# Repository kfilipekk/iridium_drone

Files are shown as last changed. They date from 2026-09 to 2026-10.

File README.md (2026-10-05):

# NAVCORE-SoOP



A 46.5 × 47.2 mm, 6-layer STM32H743 flight controller that navigates without GPS using the Doppler shift of Iridium satellites. It runs ArduPilot with a MatekH743-compatible pinout and also carries the avionics for a TVC rocket lander. Made by Krystian Filipek for my GNSS-denied drone and the Cambridge University Spaceflight Lander Challenge.

<div align="center">

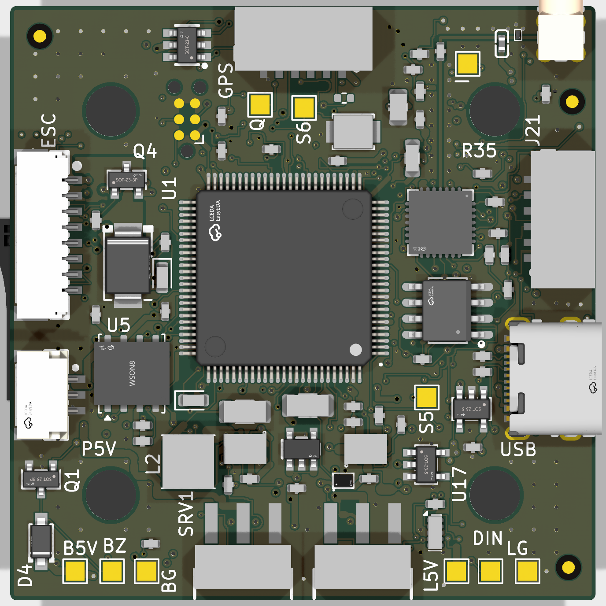
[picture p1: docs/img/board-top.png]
Board Top

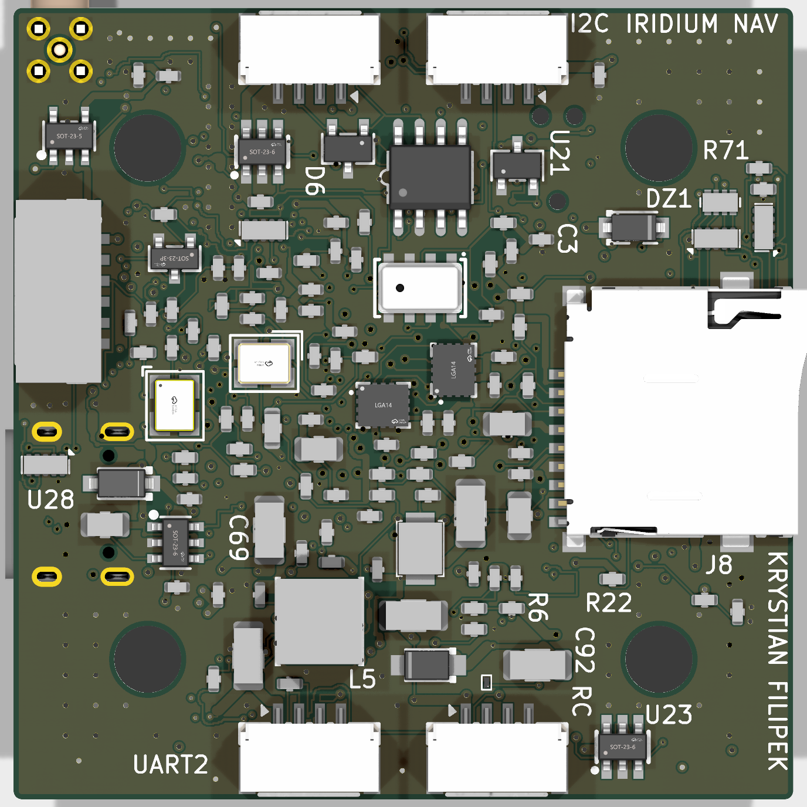
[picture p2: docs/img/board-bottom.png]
Board Bottom


</div>

## Features

### Iridium Navigation
Optical flow and visual-inertial odometry drift without bound over long flights. Iridium NEXT satellites orbit at ~780 km and ~7.5 km/s and transmit continuously at 1616-1626.5 MHz, so the Doppler shift of their bursts gives an absolute position with bounded error (typically 100-200 m) that complements the faster inertial sensors.

- **L-band Receiver** - MAX2112 direct-conversion tuner and OPA2374 baseband filter into the ADCs
- **Antenna Feed** - MMCX port with a current-limited 5 V feed for the active antenna, reported as open, ok or short
- **On-board Navigation** - burst detection, SGP4 orbits and the position solve run on the H743 and feed ArduPilot's EKF as a GPS
- **Spoofing Check** - the real GPS is checked against the Iridium-only fix before it is trusted

### Hardware
| Subsystem | Components |
|---|---|
| MCU | STM32H743VIT6, Cortex-M7 @ 480 MHz, 2 MB flash, 1 MB RAM |
| IMUs | ICM-42688-P (SPI1) and ICM-42605 (SPI4) on a separate low-noise 3.3 V rail |
| Barometer | MS5611 on I2C2 |
| Storage | W25Q128 flash for the orbit catalogue, microSD over SDIO |
| Power | 3S-5S input, TVS and reverse-polarity protection, two LMR33630 bucks (5 V 1.6 A system, 5 V 2.1 A payload) and three 3.3 V LDOs |
| Connectors | Latching JST-GH on every cable port, two servo headers, MMCX, USB-C, TC2030 SWD pads |
| Protection | ESD clamp on every cable-facing signal, series resistors on the motor, telemetry, current, lidar and servo lines |

### Layer Stackup
```
F.Cu:   RF, crystals, MCU fanout
In1.Cu: Continuous ground plane
In2.Cu: SPI, SDIO and I2C
In3.Cu: UARTs, PWM and slow I/O
In4.Cu: Power planes (+5V, +5V_PAYLOAD, +3V3, VBAT)
B.Cu:   Sensors, RF receiver, DroneCAN, bucks
```

### Supported Platforms
- **GNSS-denied Quadcopter** - 30.5 mm stack mount, DShot ESC on `J2`, optical flow on `J14`, lidar on `J11`, companion computer on `J21`, DroneCAN on `J6`
- **TVC Rocket Lander** - two servo outputs (`J17`, `J23`) on the payload rail and 6-DoF logging to microSD

### How It Compares
| | NAVCORE-SoOP | SpeedyBee F405 V4 | Matek H743-SLIM V3 | Pixhawk 6C |
|---|---|---|---|---|
| MCU | STM32H743 | STM32F405 | STM32H743 | STM32H743 + F103 |
| IMUs | ICM-42688-P + ICM-42605 | ICM-42688-P | ICM-42688-P + ICM-42605 | ICM-42688-P + BMI088 |
| Input | 3-5S | 3-6S | 2-8S | power module |
| Port ESD | every cable signal | none stated | none stated | none stated |
| Position without GNSS | Iridium Doppler, 100-200 m | none | none | none |

It has no OSD and no 9-12 V video rail, and it takes 5S at most.

## Getting Started

### Prerequisites
- **KiCad 9** with the `pcbnew` Python module
- **Python 3** with `pip install -r requirements.txt`
- **ArduPilot toolchain** for the firmware (`tools/build_firmware.sh` pins Copter-4.7.0)

### Checking the Board
1. Clone the repository:
   ```bash
   git clone https://github.com/kfilipekk/iridium_drone.git
   cd iridium_drone
   ```

2. Run KiCad's own checks:
   ```bash
   kicad-cli pcb drc --severity-error NAVCORE-SoOP.kicad_pcb
   kicad-cli sch erc NAVCORE-SoOP.kicad_sch
   ```

3. Run the board checks:
   ```bash
   python3 tools/check_design.py
   python3 tools/check_connectors.py
   python3 tools/check_power_cut.py
   python3 tools/check_ratings.py
   ```

4. Build the firmware:
   ```bash
   bash tools/build_firmware.sh
   ```

### Ordering
The JLCPCB files are in `fab/`: the Gerber and drill bundle, BOM, pick-and-place and schematic PDF. Order 6 layers, 1 oz outer copper, no impedance control, epoxy-filled and capped vias, ENIG, and top and bottom assembly.

## Repository Structure

```
├── NAVCORE-SoOP.kicad_pcb   # PCB
├── NAVCORE-SoOP.kicad_sch   # Schematic, generated from tools/design.py
├── fab/                     # JLCPCB order files
├── firmware/                # ArduPilot hwdef, the SoOP backend and the on-board navigation
├── tools/                   # Design model, generators and checks
├── cad/                     # OpenSCAD airframe and clearance models
├── sim/                     # SPICE decks for the analogue blocks
├── sitl/                    # ArduPilot SITL scenarios
└── libraries/               # Footprint and symbol libraries
```

## Applications

I made this project to explore:
- Navigation from signals of opportunity instead of GPS
- Six-layer mixed-signal PCB design with an RF front end
- ArduPilot drivers and EKF integration
- Automated checks for a hardware design

## Future Plans

- Bench-test the Iridium receive chain with the HC610 antenna
- Rev E: a third IMU, 6S input and a 9-12 V video rail

<div align="center">

Developed by [kfilipekk](https://github.com/kfilipekk)

</div>

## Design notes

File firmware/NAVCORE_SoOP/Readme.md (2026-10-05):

# NAVCORE_SoOP

ArduPilot hardware definition for the NAVCORE-SoOP flight controller.

## Introduction

NAVCORE-SoOP is a 46.5 x 47.2 mm, 6-layer STM32H743 flight controller built to test
navigation without GPS. It works out position from the Doppler shift of Iridium satellite
signals, which is a rough but *absolute* fix, so the error stays bounded instead of growing
with time the way a camera or flow-based estimate does.

The pinout follows the MatekH743 wherever the layout allowed, so stock ArduPilot MatekH743
binaries boot on it for bring-up, on one IMU (see IMU Orientation). This hwdef gives the
board its own ID, reaches both IMUs with the right rotations, and describes only the hardware
that is actually populated.

Project repository: <https://github.com/kfilipekk/iridium_drone>

## Features and Specifications

* Processor: STM32H743VIT6, 480 MHz, LQFP-100
* Flash for logging: microSD (SDMMC1, 4-bit) and a W25Q128 16 MB SPI flash used for the
  Iridium TLE catalogue
* IMUs: ICM-42688-P (SPI1) and ICM-42605 (SPI4), both on their own 3.3 V analogue rail
* Barometer: MS5611 (I2C, address 0x77)
* Compass: none on board, external I2C compass on the GPS connector
* SoOP receiver: MAX2112 L-band tuner (I2C2) and OPA2374 baseband amplifiers into ADC1/ADC2,
  with a current-limited, monitored 5 V feed to the active antenna on the MMCX port
* Power: 3S to 5S input, reverse-polarity protected; a 5 V buck for the board, a second
  switchable 5 V buck for payloads, and 3.3 V regulators
* Protection: every cable-facing signal is clamped at its connector
* Physical: 46.5 x 47.2 mm, 30.5 mm stack pattern, 1.6 mm, 6 layers

There is no on-board compass and no analogue OSD chip by design.

## Where to Buy

Not commercially available. NAVCORE-SoOP is an open-source hardware project; the design
files are in the repository linked above and there is no vendor.

## Pinout

### Connectors

Every cable port is a latching JST-GH 1.25 mm connector.

| Reference | Type | Function |
| --- | --- | --- |
| J1 | USB-C | USB, ESD protected |
| J2 | JST-GH 8P | 4-in-1 ESC: power, motors, current, telemetry |
| J3 | JST-GH 6P | GPS and external compass: 5 V, TX, RX, SCL, SDA, GND |
| J5 | JST-GH 4P | RC receiver: 5 V, TX, RX, GND |
| J6 | JST-GH 4P | CAN1: 5 V payload, CANH, CANL, GND |
| J8 | microSD | Logging |
| J9 | JST-GH 4P | I2C1: 5 V, SCL, SDA, GND |
| J11 | JST-GH 4P | SERIAL2: 5 V payload, TX, RX, GND |
| J12 | MMCX | SoOP antenna, with 5 V for its LNA |
| J14 | JST-GH 6P | SPI3 optical flow: 3.3 V, SCK, MISO, MOSI, CS, GND |
| J17 | 1x3 2.54 mm header | Servo 1: PWM7, 5 V payload, GND |
| J19 | Tag-Connect TC2030 | SWD: 3.3 V, SWDIO, NRST, SWCLK, GND |
| J21 | JST-GH 6P | SERIAL1 (UART7), Pixhawk TELEM order: 5 V, TX, RX, CTS, RTS, GND |
| J22 | JST-GH 3P | Payload 5 V for a camera or VTX |
| J23 | 1x3 2.54 mm header | Servo 2: PWM8, 5 V payload, GND |

The LED strip and the buzzer are on solder pads (5 V, data or drain, GND).

### J2, the ESC connector

| Pin | Signal |
| --- | --- |
| 1 | GND |
| 2 | VBAT |
| 3 | Motor 1 |
| 4 | Motor 2 |
| 5 | Motor 3 |
| 6 | Motor 4 |
| 7 | Current sense |
| 8 | ESC telemetry (RX only) |

This matches the Betaflight pin order for the SpeedyBee F405 V4.

## UART Mapping

| Serial | Protocol | Port | Notes |
| --- | --- | --- | --- |
| SERIAL0 | OTG1 | USB | |
| SERIAL1 | Telem1 | UART7 | J21, with CTS/RTS |
| SERIAL2 | Spare | USART1 | J11 |
| SERIAL3 | GPS1 | USART2 | Default GPS, on J3 |
| SERIAL4 | Spare | USART3 | Not brought out on this board |
| SERIAL5 | ESC telemetry | UART8 | RX only, pin 8 of J2 |
| SERIAL6 | | EMPTY | Unassigned: UART4's pins carry PWM5 and PWM7 |
| SERIAL7 | RCin | USART6 | CRSF/ELRS, on J5 |
| SERIAL8 | OTG2 | Not connected | |

## PWM Outputs

Four motor outputs on J2, DShot capable. `MOT_PWM_TYPE` defaults to 6 (DShot600) and the
frame is `FRAME_CLASS 1`, `FRAME_TYPE 1`. Motors 1-2 are on TIM3 and 3-4 on TIM5, each
timer with DMA of its own, so bidirectional DShot works on all four: flash Bluejay to the
ESC, then set `SERVO_BLH_BDMASK` to 15.

PWM 5 and 6 are on test pads TP3 and TP4. PWM 7 and 8 (TIM4) are on the servo headers J17
and J23. PWM 11 and 12 are not brought out.

PWM(13) on PA8 drives an addressable LED strip through a buffer, and `SERVO13_FUNCTION`
defaults to 120 for that purpose.

## RC Input

Connect the RC receiver to J5, which is a JST-GH 1.25 mm 4-pin connector carrying 5 V,
TX, RCin and GND. `SERIAL7_PROTOCOL` defaults to 23, which is CRSF, so CRSF and ELRS
receivers work with no parameter change.

For uni-directional protocols such as SBUS and FPort, set `RC_PROTOCOLS` to 1 to return to
auto-detection. This board provides no dedicated SBUS inverter or RCin pad; all RC input
arrives on the J5 UART.

## Payload Power

A second 5 V buck feeds the payload connectors (J6, J11, J17, J22, J23) and the LED strip
pad. GPIO 83 switches it and is `RELAY1_PIN` with `RELAY1_DEFAULT 0`. The switch is inverted: pin low
leaves the rail on, so the payload is powered from boot. Setting the relay turns it off.

## GPIOs

| GPIO | Pin | Function |
| --- | --- | --- |
| 83 | PA7 | Payload 5 V rail, low = on, `RELAY1_PIN` |
| 84 | PC5 | Antenna 5 V feed enable, high = on from boot |
| 85 | PD10 | Antenna feed fault, from the load switch |
| 86 | PD11 | Not wired, pulled down (reserved for a flow sensor's motion line) |

## CAN

CAN1 is on J6 through an SN65HVD230 transceiver, with `GPIO_CAN1_SILENT` on PD3. The bus
is not terminated on the board. Fit R15 (120 ohm) if the board is at one end of the bus.

## IMU Orientation

Both IMUs are on the bottom of the board. The hwdef declares `ROTATION_YAW_180` for the
ICM-42688-P and `ROTATION_YAW_90` for the ICM-42605, worked out from the footprint pads,
with forward as marked by the silkscreen arrow.

The ICM-42605's chip select is PE11, the pin MatekH743 gives its ICM-20602, so stock
MatekH743 firmware finds only the ICM-42688-P. Check the attitude on the bench before
flying stock firmware, and set `AHRS_ORIENTATION` if it is off.

## RSSI, Airspeed and Analog Pins

There are no user analog inputs and no airspeed pin on this board. RSSI arrives over CRSF
and requires no analog pin. ADC1/ADC2 sample the SoOP receiver's I and Q, and ADC3 the
battery and the antenna feed current.

## Battery Monitoring

The board has an internal voltage sensor and takes current from the ESC's shunt on J2,
pin 7. It is rated for 3S to 5S packs.

The default battery parameters are:

* `BATT_MONITOR` = 4
* `BATT_VOLT_PIN` = 10
* `BATT_CURR_PIN` = 11
* `BATT_VOLT_MULT` = 11.0
* `BATT_AMP_PERVLT` = 25.0

`BATT_AMP_PERVLT` is derived from the ESC's published 40 mV/A scale, with no divider on
this board. It is a property of the current sensor in the ESC and will need to be adjusted
for whichever ESC is attached, or calibrated against a known load.

## Compass

NAVCORE-SoOP does not have a built-in compass, but you can attach an external compass using
I2C on the SDA and SCL pins of the J3 connector, which is the same connector as the GPS.
An external compass is the intended configuration, because a magnetometer placed on this
board would sit within a few millimetres of a 60 A ESC.

## Firmware

Firmware for this board can be found at <https://firmware.ardupilot.org> in the
sub-folder labelled `NAVCORE_SoOP`.

## Loading Firmware

This board does not ship with firmware. Hold BOOT while pressing RESET to start the
STM32's built-in DFU loader (USB ID 0483:df11), then flash the `_with_bl.hex` build following
<https://ardupilot.org/copter/docs/common-loading-firmware-onto-chibios-only-boards.html>.
J19 (SWD) is the fallback if DFU never appears.

## Other Links

* Project repository: <https://github.com/kfilipekk/iridium_drone>
* Board pin map and assembly notes: in the repository under `docs/`

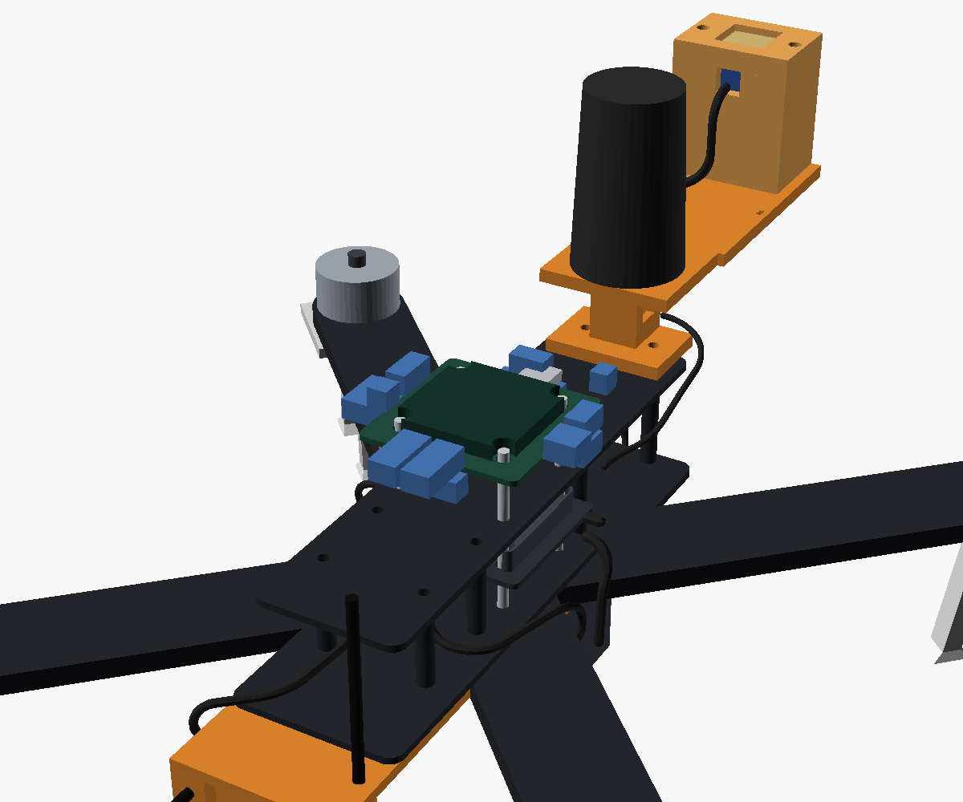
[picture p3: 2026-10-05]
cad/renders/exploded.png

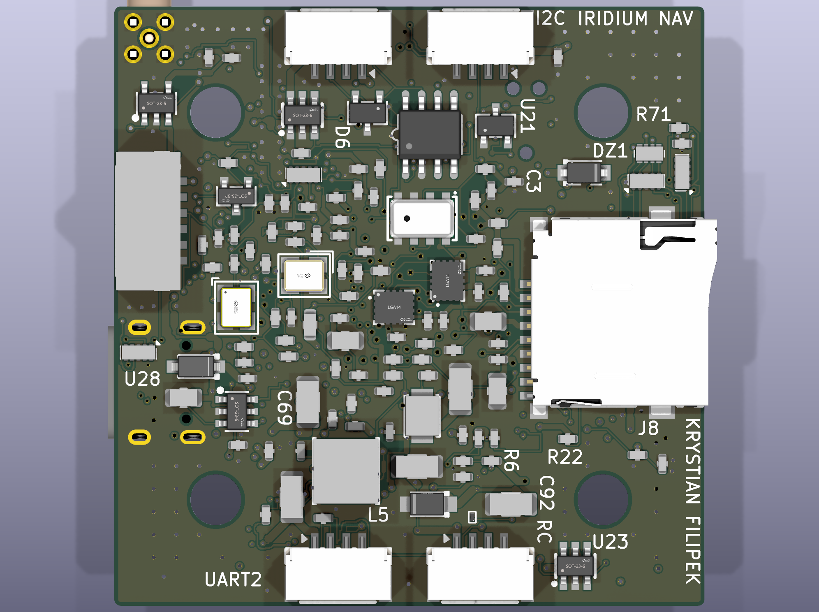
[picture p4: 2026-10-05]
docs/img/render-bottom-flat.png

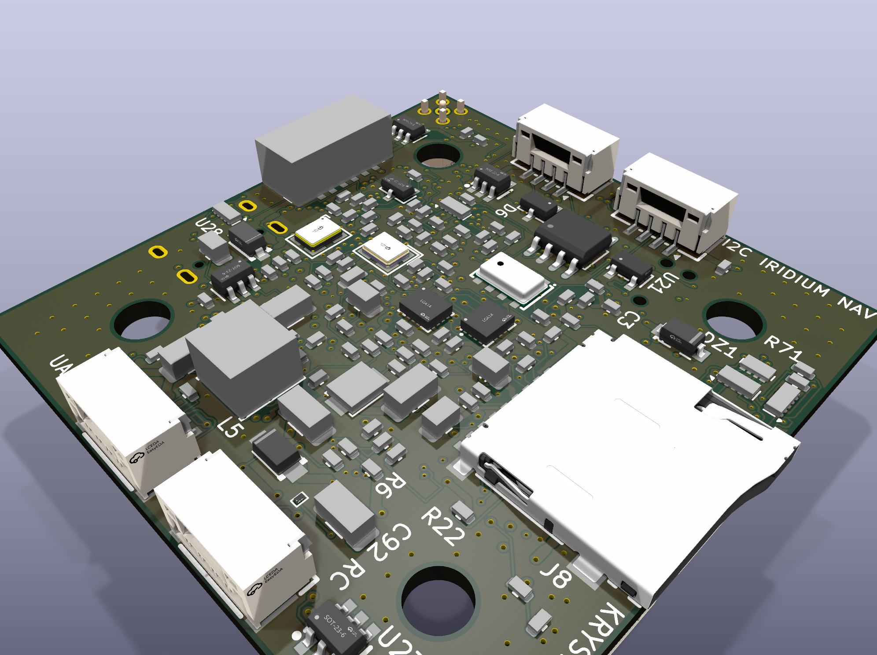
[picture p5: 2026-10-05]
docs/img/render-iso-bottom.png

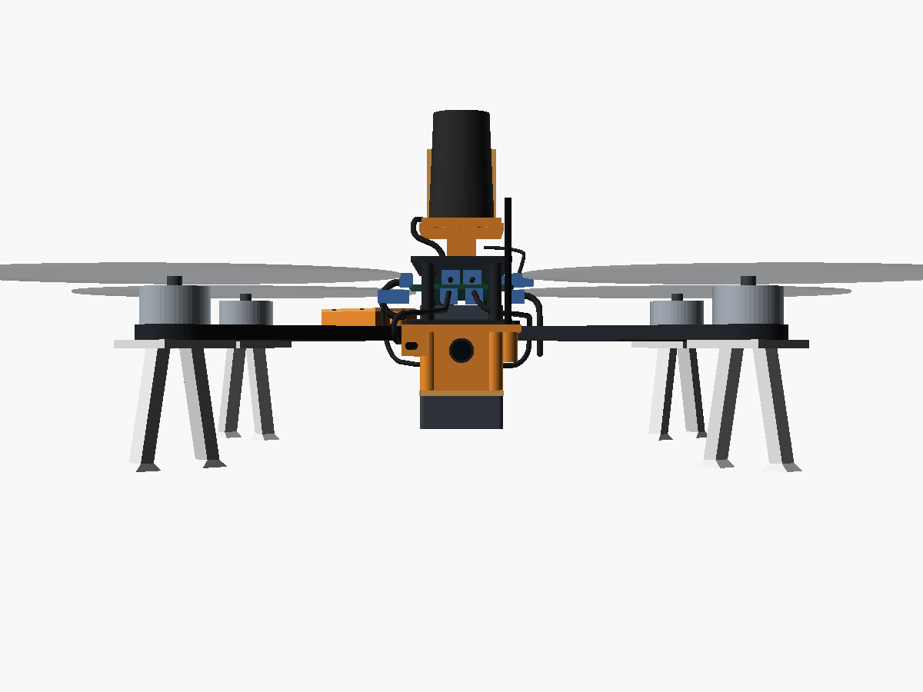
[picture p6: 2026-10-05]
cad/renders/front.png

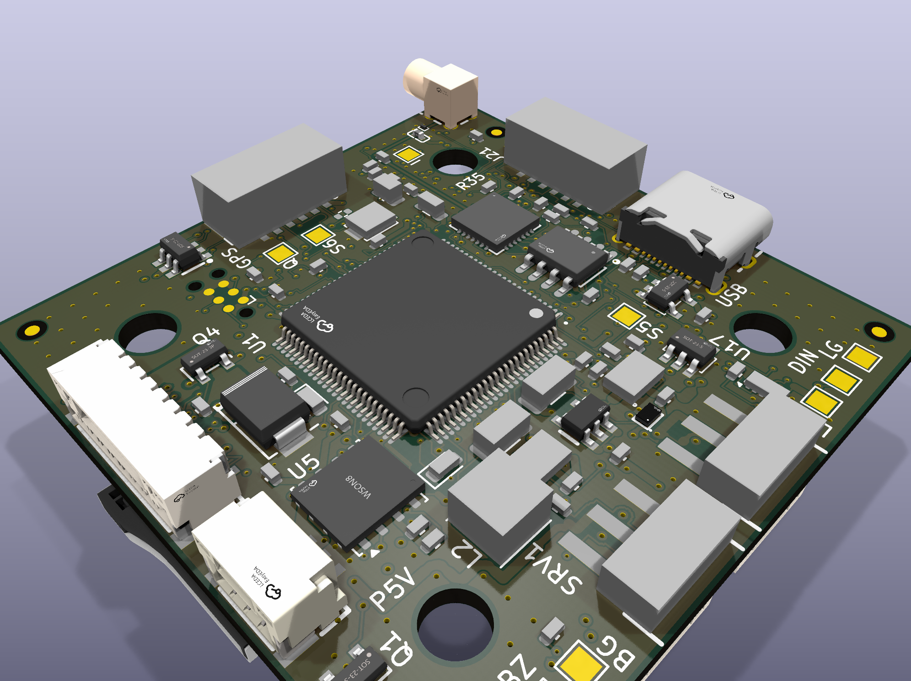
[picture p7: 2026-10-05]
docs/img/render-iso.png

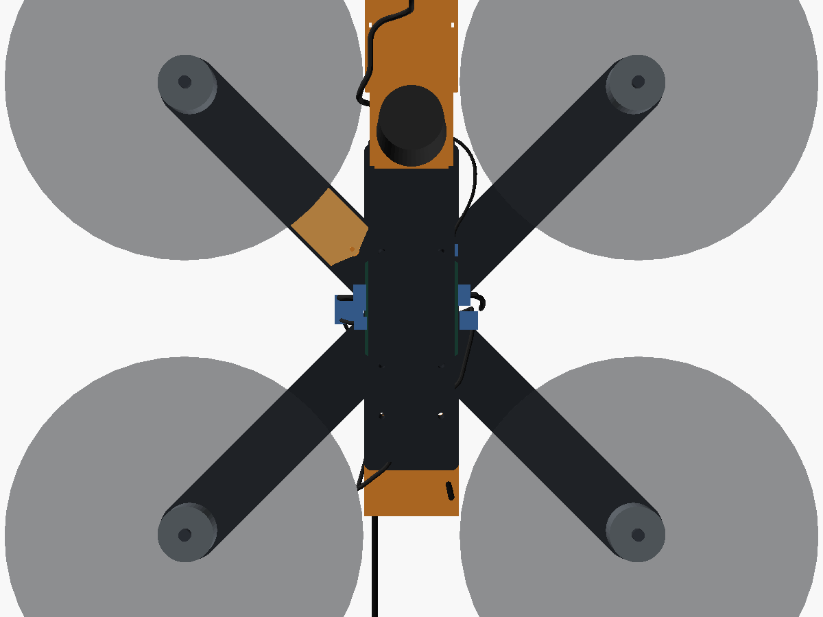
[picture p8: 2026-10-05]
cad/renders/top.png

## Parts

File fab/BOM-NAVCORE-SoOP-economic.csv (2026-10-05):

Comment | Designator | Footprint | LCSC | Qty | DNP
100n | C1,C10,C12,C14,C2,C21,C3,C30,C31,C32,C33,C34,C35,C36,C4,C41,C43,C44,C46,C49,C5,C50,C57,C59,C60,C65,C68,C74,C88,C89,C90,C94,C95,C96 | C_0402_1005Metric | C1525 | 34
10k | R1,R14,R39,R45,R48,R49,R50,R51,R52,R53,R59,R60 | R_0402_1005Metric | C25744 | 12
1u | C11,C13,C26,C27,C28,C51,C67,C75,C78,C79,C80 | C_0402_1005Metric | C52923 | 11
4k7 | R10,R11,R12,R31,R36,R37,R47,R58,R9 | R_0402_1005Metric | C25900 | 9
47k | R22,R23,R24,R25,R26,R27 | R_0402_1005Metric | C25792 | 6
100R | R38,R70,R72,R73,R74,R75 | R_0402_1005Metric | C25076 | 6
100k | R4,R40,R42,R46,R6 | R_0402_1005Metric | C25741 | 5
22u | C22,C23,C69,C70,C92 | C_1206_3216Metric | C5177178 | 5
TPD4E05U06 | U26,U27,U28,U29,U30 | USON-10_2.5x1.0mm_P0.5mm | C138714 | 5
1k | R19,R20,R21,R35 | R_0402_1005Metric | C11702 | 4
100p | C52,C56,C76,C77 | C_0402_1005Metric | C1546 | 4
2u2 | C29,C8,C9 | C_0402_1005Metric | C12530 | 3
1n | C81,C84,C86 | C_0402_1005Metric | C1523 | 3
LMR33630A | U20,U8 | VQFN-12_L3.0-W2.0-P0.65-BL_TI_RNX | C2861505 | 2
4u7 | C6,C7 | C_0805_2012Metric | C354262 | 2
30p | C15,C16 | C_0402_1005Metric | C107004 | 2
10u | C17,C18 | C_1206_3216Metric | C13585 | 2
100n | C19,C66 | C_0402_1005Metric | C131394 | 2
22k | R41,R5 | R_0402_1005Metric | C25767 | 2
24k9 | R43,R7 | R_0402_1005Metric | C25874 | 2
5k1 | R16,R17 | R_0402_1005Metric | C25905 | 2
10u | C45,C93 | C_0805_2012Metric | C1713 | 2
0R | R28,R29 | R_0402_1005Metric | C17168 | 2
10n | C58,C73 | C_0402_1005Metric | C15195 | 2
47n | C61,C63 | C_0402_1005Metric | C82219 | 2
AO3400A | Q1,Q3 | SOT-23-3_L2.9-W1.3-P1.90-LS2.4-BR | C20917 | 2
SRV05-4 | U22,U23 | SOT-23-6_L2.9-W1.6-P0.95-LS2.8-BR | C6454456 | 2
PESD5V0C1BSF | D7,D9 | DSN0603-2_L0.6-W0.3-P0.40-BI | C477955 | 2
STM32H743VIT6 | U1 | LQFP-100_L14.0-W14.0-P0.50-LS16.0-BL | C5271084 | 1
ICM-42688-P | U2 | LGA-14_L3.0-W2.5-P0.50-TL | C1850418 | 1
ICM-42605 | U3 | LGA-14_L3.0-W2.5-P0.50-TL | C2655099 | 1 | DNP
MS5611 | U4 | SENSORS-SMD_MS5611-01BA03 | C15639 | 1
W25Q128JVPIQ | U5 | WSON-8-1EP_6x5mm_P1.27mm_EP3.4x4.3mm | C190862 | 1
TLV75733P | U9 | SOT-23-5_L2.9-W1.6-P0.95-LS2.8-BL-EP | C22399950 | 1
TLV75533 | U10 | SOT-23-5_L3.0-W1.7-P0.95-LS2.8-BR | C404027 | 1
SN65HVD230 | U11 | SOIC-8_L4.9-W3.9-P1.27-LS6.0-BL | C12084 | 1
USBLC6-2SC6 | U12 | SOT-23-6_L2.9-W1.6-P0.95-LS2.8-BL | C2687116 | 1
USB-C | J1 | USB-C-SMD_TYPE-C-16PIN-2MD-073 | C2765186 | 1
ESC 8P | J2 | CONN-SMD_SM08B-GHS-TB-LF-SN | C42376901 | 1
GPS+I2C | J3 | CONN-SMD_XY-SM06B-GHS-TB | C51940119 | 1
RC IN | J5 | CONN-SMD_4P-P1.25_BX-GH1.25-4PWT | C18077720 | 1
CAN 4P | J6 | CONN-SMD_4P-P1.25_BX-GH1.25-4PWT | C18077720 | 1
microSD | J8 | TF-SMD_TF-01A | C91145 | 1
8MHz | Y1 | CRYSTAL-SMD_4P-L3.2-W2.5-BL | C2682774 | 1
SMBJ22A | D1 | SMB_L4.6-W3.6-LS5.3-RD | C113993 | 1
MAX2112 | U13 | TQFN-28_L5.0-W5.0-P0.50-BL-EP3.3 | C596391 | 1
OPA2374 | U14 | SOP-8_L4.9-W3.9-P1.27-LS6.0-BL | C444392 | 1
25MHz TCXO | Y2 | OSC-SMD_4P-L3.2-W2.5-BL | C5563878 | 1
600R@100MHz | L1 | L_0805_2012Metric | C18305 | 1
10uH | L2 | L_APV_ANR4030 | C167879 | 1
120R | R15 | R_0402_1005Metric | C25862 | 1 | DNP
1u | C42 | C_0805_2012Metric | C91185 | 1
10k | R18 | R_0603_1608Metric | C25804 | 1
BLUE | D2 | LED_0603_1608Metric | C965807 | 1
GREEN | D3 | LED_0603_1608Metric | C965804 | 1
BOOT | SW1 | SW_SPST_B3U-1000P | C231329 | 1
RESET | SW2 | SW_SPST_B3U-1000P | C231329 | 1
330R | R34 | R_0402_1005Metric | C25104 | 1
470R | R57 | R_0402_1005Metric | C25117 | 1
COMPANION | J21 | CONN-SMD_XY-SM06B-GHS-TB | C51940119 | 1
1N4148W | D4 | SOD-123F_L2.7-W1.6-LS3.8-RD | C81598 | 1
10uH | L5 | L_APV_ANR5040 | C354610 | 1
PAYLOAD 5V | J22 | CONN-TH_SM03B-GHS-TB-LF-SN | C514175 | 1
74LVC1G17 | U17 | SOT-23-5_L3.0-W1.7-P0.95-LS2.8-BR | C7836 | 1
XC6206P332MR | U21 | SOT-23-3_L2.9-W1.6-P1.90-LS2.8-BR | C5446 | 1
PESD2CANFD24LT | D6 | SOT-23-3_L2.9-W1.6-P1.90-LS2.8-BR | C6952426 | 1
FLOW 6P | J14 | CONN-SMD_XY-SM06B-GHS-TB | C51940119 | 1
SERVO1 | J17 | HDR-SMD_3P-P2.54-H-M_KH-2.54PH-1X3P-L13.5-WT | C20610212 | 1
SERVO2 | J23 | HDR-SMD_3P-P2.54-H-M_KH-2.54PH-1X3P-L13.5-WT | C20610212 | 1
PTVS5V0S1UR | D8 | SOD-123FL_L2.7-W1.8-LS3.8-RD | C5380694 | 1
AP22653 | U24 | SOT-23-6_L2.9-W1.6-P0.95-LS2.8-BR | C2158037 | 1
210k | R61 | R_0402_1005Metric | C58827 | 1
2R2 | R62 | R_0402_1005Metric | C25101 | 1
INA180A2 | U25 | SOT-23-5_L3.0-W1.7-P0.95-LS2.8-BL | C192764 | 1
10p | C91 | C_0402_1005Metric | C32949 | 1
27nH | L6 | L0402 | C113111 | 1
B5819W | D_USB | SOD-123_L2.7-W1.6-LS3.7-RD-1 | C8598 | 1
MMCX-KWE-90 | J12 | MMCX-TH_DL-MMCX-KWE-90 | C2894793 | 1
TMP119 | U19 | DSBGA-6_L1.5-W1.0-R2-C3-P0.40-BL | C22428347 | 1
WST4041 | Q4 | SOT-23-3_L2.9-W1.3-P1.90-LS2.4-BR | C148357 | 1
BZT52C15 | DZ1 | SOD-123_L2.7-W1.6-LS3.7-RD | C173427 | 1
I2C 4P | J9 | CONN-SMD_4P-P1.25_BX-GH1.25-4PWT | C18077720 | 1
SERIAL2 4P | J11 | CONN-SMD_4P-P1.25_BX-GH1.25-4PWT | C18077720 | 1
33R x4 | RN1 | R_Array_Convex_4x0402 | C25501 | 1
2k2 | R71 | R_0402_1005Metric | C25879 | 1

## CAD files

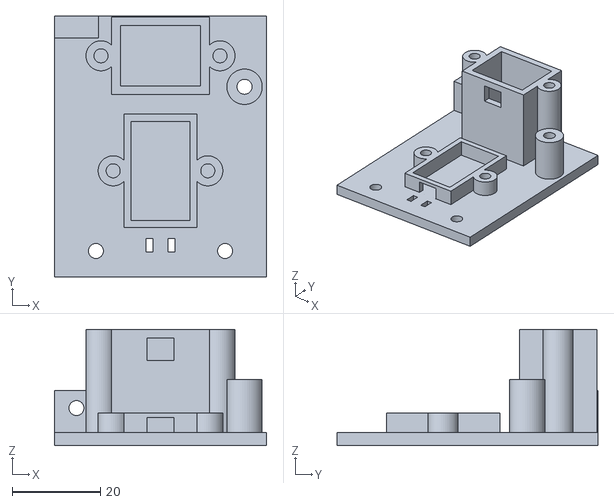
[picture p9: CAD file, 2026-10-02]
cad/print/nose_mount.stl
48.0 x 59.0 x 26.3

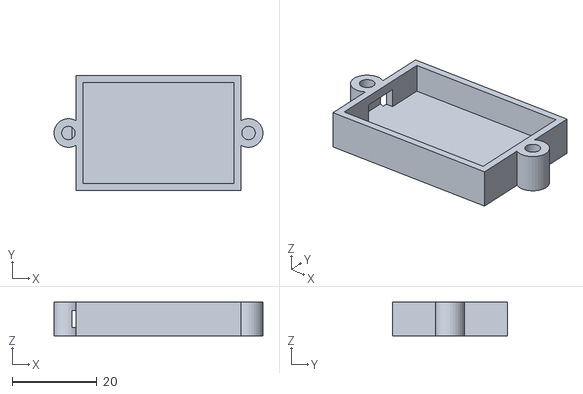
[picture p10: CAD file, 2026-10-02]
cad/print/rid_tray.stl
49.3 x 27.1 x 8.00

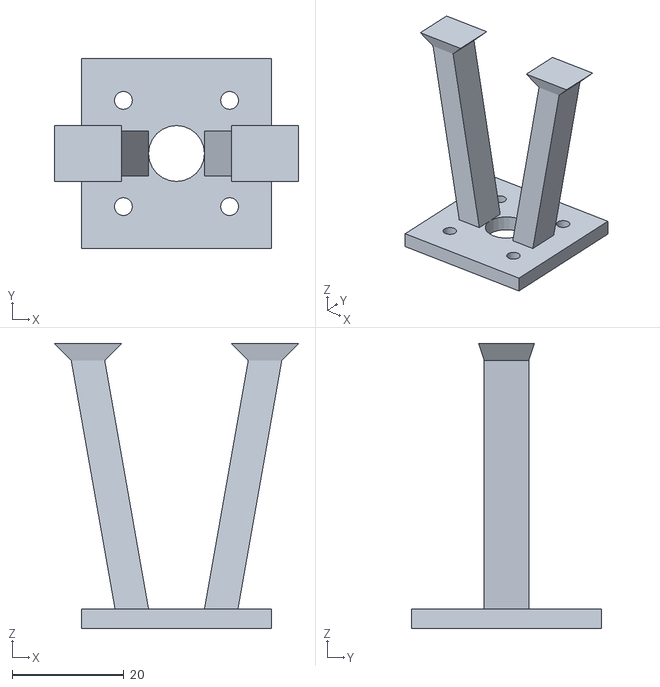
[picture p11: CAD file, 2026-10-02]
cad/print/skid.stl
43.7 x 34.0 x 51.0

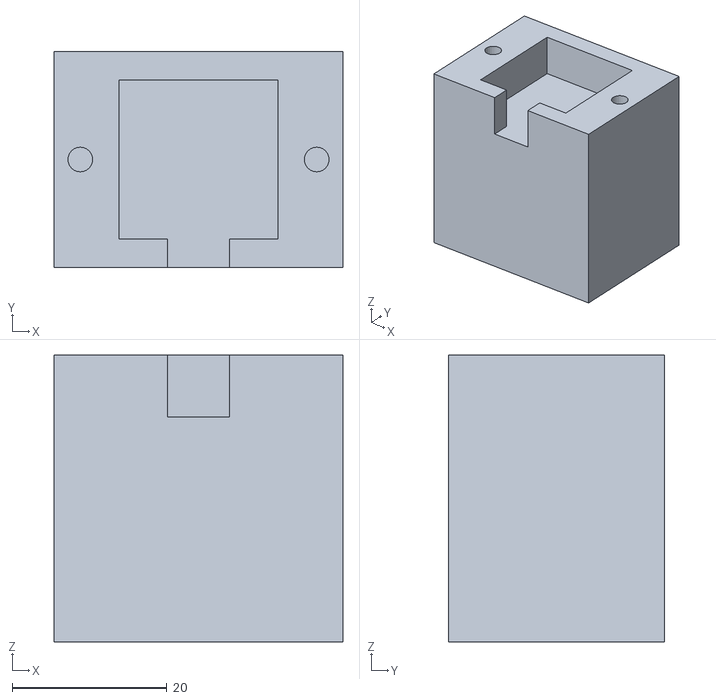
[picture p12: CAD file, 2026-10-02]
cad/print/gps_pod.stl
37.4 x 28.0 x 37.1

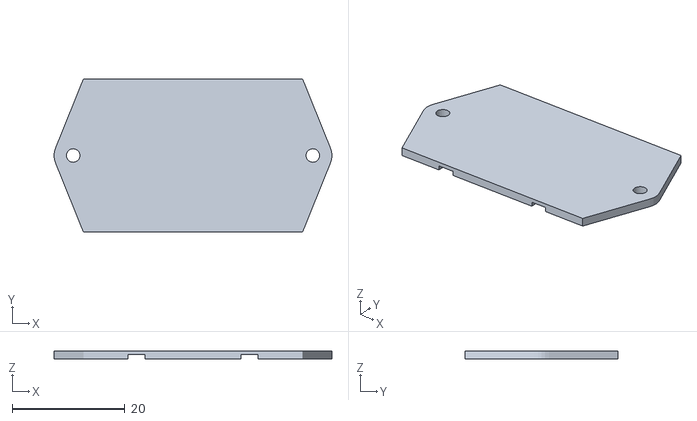
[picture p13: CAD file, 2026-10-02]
cad/print/rid_cover.stl
49.3 x 27.1 x 1.50

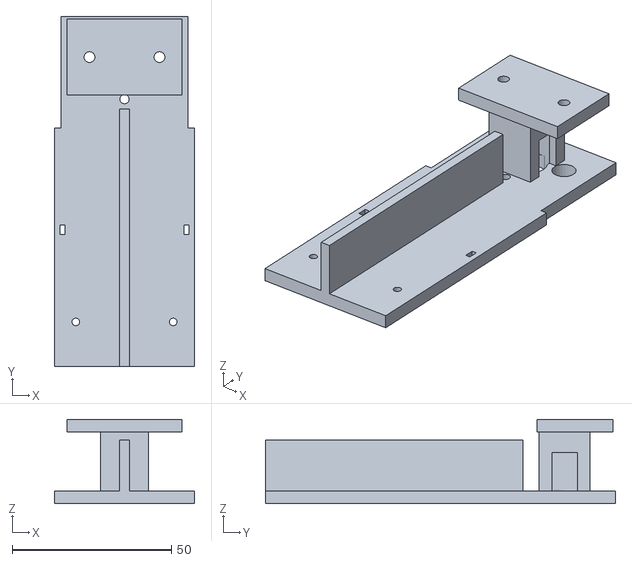
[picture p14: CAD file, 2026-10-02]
cad/print/antenna_tower.stl
44.0 x 110.0 x 26.5

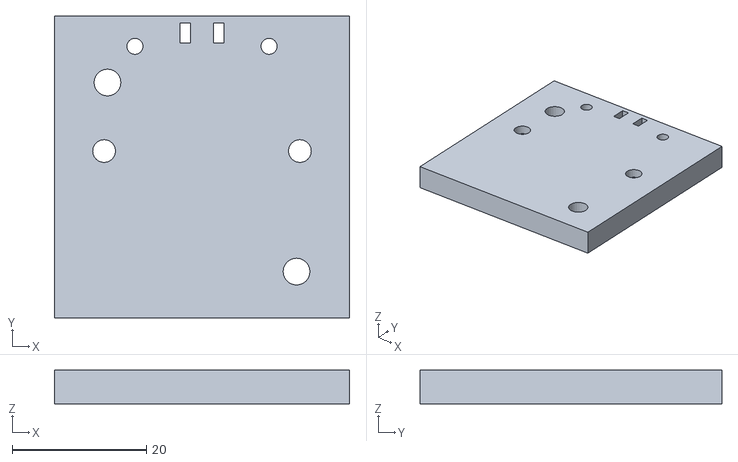
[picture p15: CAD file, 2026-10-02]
cad/print/lidar_bracket.stl
44.0 x 45.0 x 5.00

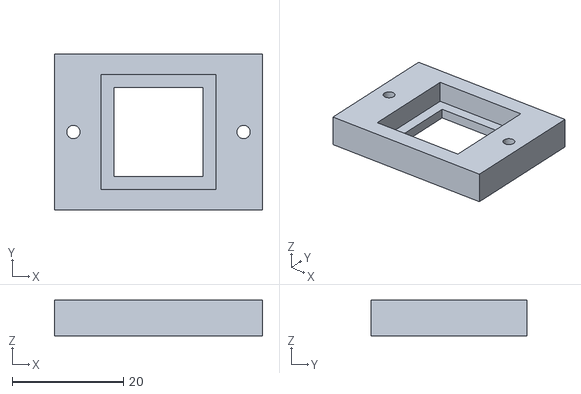
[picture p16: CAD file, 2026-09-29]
cad/print/gps_lid.stl
37.4 x 28.0 x 6.40

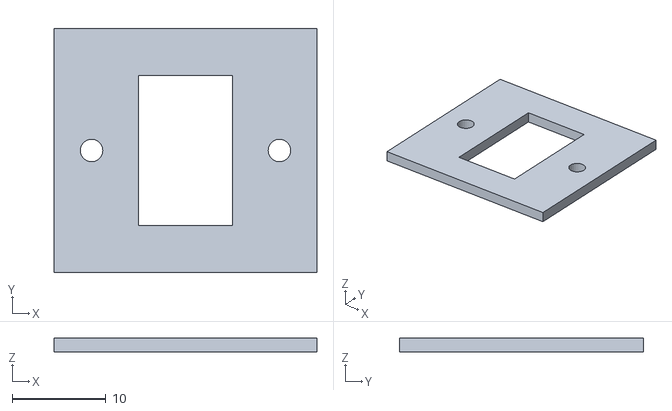
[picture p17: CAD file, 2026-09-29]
cad/print/range_lid.stl
28.0 x 26.0 x 1.50

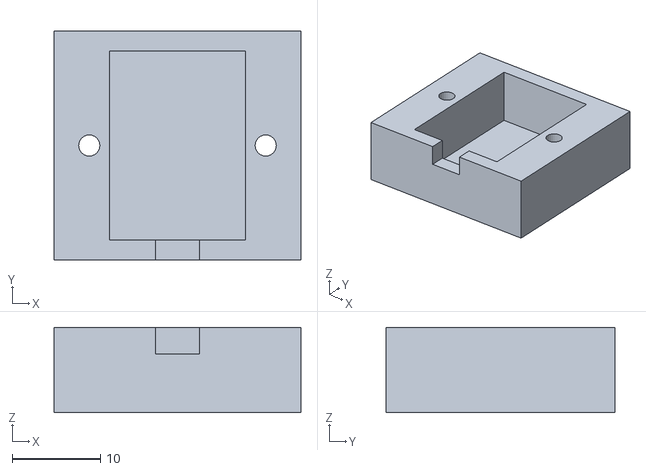
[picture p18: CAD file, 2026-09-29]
cad/print/range_cradle.stl
28.0 x 26.0 x 9.67

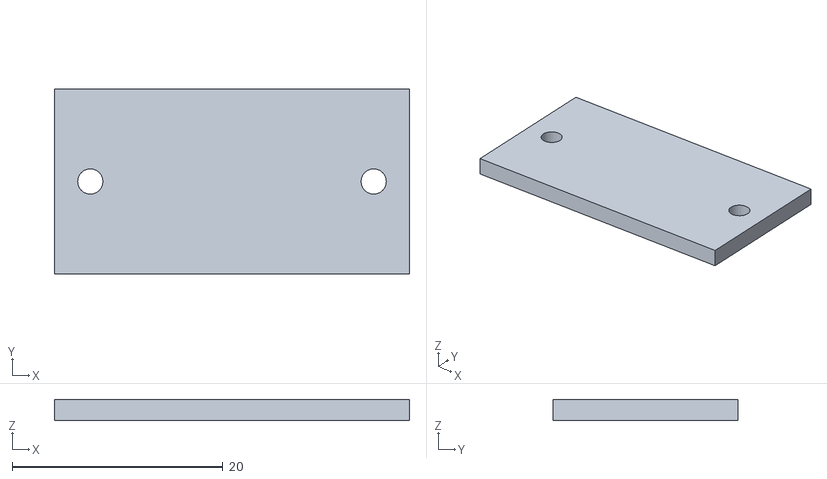
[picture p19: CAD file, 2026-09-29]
cad/print/xiao_lid.stl
33.7 x 17.6 x 2.00

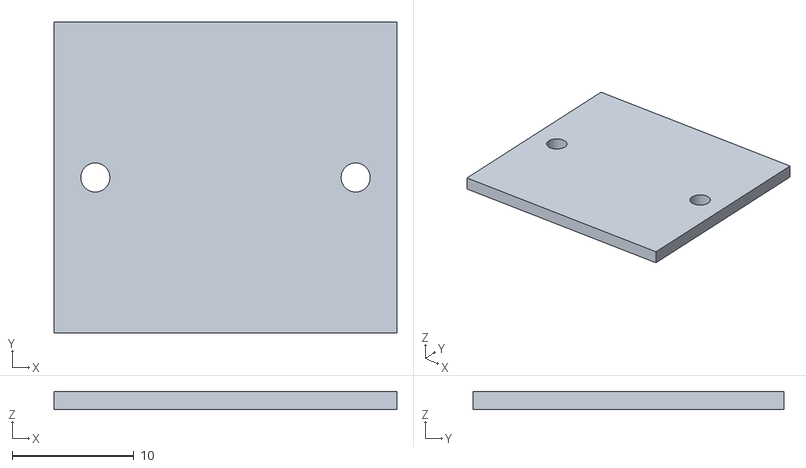
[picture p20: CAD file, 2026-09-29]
cad/print/rx_cover.stl
28.2 x 25.6 x 1.50

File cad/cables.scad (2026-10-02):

// GENERATED by the cable check - DO NOT EDIT.
// Each lead along the full-radius filleted path the cable check checks,
// at its bundle's diameter. A lead whose far end is undefined stops where its
// known run does.

module lead(pts, r) {
    for (i = [0 : len(pts) - 2]) hull() {
        translate(pts[i]) sphere(r = r, $fn = 8);
        translate(pts[i + 1]) sphere(r = r, $fn = 8);
    }
}

module cables() {
    color("#222222") lead([[-27.70, 5.40, 29.50], [-28.21, 5.40, 29.50], [-28.73, 5.40, 29.50], [-28.73, 5.40, 29.50], [-29.21, 5.40, 29.49], [-29.21, 5.40, 29.49], [-29.69, 5.40, 29.44], [-29.69, 5.40, 29.44], [-30.16, 5.40, 29.37], [-30.16, 5.40, 29.37], [-30.63, 5.40, 29.27], [-30.63, 5.40, 29.27], [-31.10, 5.40, 29.14], [-31.10, 5.40, 29.14], [-31.55, 5.40, 28.98], [-31.55, 5.40, 28.98], [-32.00, 5.40, 28.80], [-32.00, 5.40, 28.80], [-32.43, 5.40, 28.59], [-32.43, 5.40, 28.59], [-32.85, 5.40, 28.35], [-32.85, 5.40, 28.35], [-33.26, 5.40, 28.09], [-33.26, 5.40, 28.09], [-33.64, 5.40, 27.80], [-33.64, 5.40, 27.80], [-34.01, 5.40, 27.49], [-34.01, 5.40, 27.49], [-34.36, 5.40, 27.16], [-34.36, 5.40, 27.16], [-34.69, 5.40, 26.81], [-34.69, 5.40, 26.81], [-35.00, 5.40, 26.44], [-35.00, 5.40, 26.44], [-35.29, 5.40, 26.06], [-35.29, 5.40, 26.06], [-35.55, 5.40, 25.65], [-35.55, 5.40, 25.65], [-35.79, 5.40, 25.23], [-35.79, 5.40, 25.23], [-36.00, 5.40, 24.80], [-36.00, 5.40, 24.80], [-36.18, 5.40, 24.35], [-36.18, 5.40, 24.35], [-36.34, 5.40, 23.90], [-36.34, 5.40, 23.90], [-36.47, 5.40, 23.43], [-36.47, 5.40, 23.43], [-36.57, 5.40, 22.96], [-36.57, 5.40, 22.96], [-36.64, 5.40, 22.49], [-36.64, 5.40, 22.49], [-36.69, 5.40, 22.01], [-36.69, 5.40, 22.01], [-36.70, 5.40, 21.53], [-36.70, 5.40, 21.53], [-36.70, 5.40, 21.53], [-36.70, 5.40, 21.53], [-36.69, 5.40, 21.04], [-36.69, 5.40, 21.04], [-36.64, 5.40, 20.56], [-36.64, 5.40, 20.56], [-36.57, 5.40, 20.09], [-36.57, 5.40, 20.09], [-36.47, 5.40, 19.62], [-36.47, 5.40, 19.62], [-36.34, 5.40, 19.15], [-36.34, 5.40, 19.15], [-36.18, 5.40, 18.70], [-36.18, 5.40, 18.70], [-36.00, 5.40, 18.25], [-36.00, 5.40, 18.25], [-35.79, 5.40, 17.82], [-35.79, 5.40, 17.82], [-35.55, 5.40, 17.40], [-35.55, 5.40, 17.40], [-35.29, 5.40, 16.99], [-35.29, 5.40, 16.99], [-35.00, 5.40, 16.61], [-35.00, 5.40, 16.61], [-34.69, 5.40, 16.24], [-34.69, 5.40, 16.24], [-34.36, 5.40, 15.89], [-34.36, 5.40, 15.89], [-34.01, 5.40, 15.56], [-34.01, 5.40, 15.56], [-33.64, 5.40, 15.25], [-33.64, 5.40, 15.25], [-33.26, 5.40, 14.96], [-33.26, 5.40, 14.96], [-32.85, 5.40, 14.70], [-32.85, 5.40, 14.70], [-32.43, 5.40, 14.46], [-32.43, 5.40, 14.46], [-32.00, 5.40, 14.25], [-32.00, 5.40, 14.25], [-31.55, 5.40, 14.07], [-31.55, 5.40, 14.07], [-31.10, 5.40, 13.91], [-31.10, 5.40, 13.91], [-30.63, 5.40, 13.78], [-30.63, 5.40, 13.78], [-30.16, 5.40, 13.68], [-30.16, 5.40, 13.68], [-29.69, 5.40, 13.61], [-29.69, 5.40, 13.61], [-29.21, 5.40, 13.56], [-29.21, 5.40, 13.56], [-28.73, 5.40, 13.55], [-28.73, 5.40, 13.55], [-28.08, 5.40, 13.55], [-27.44, 5.40, 13.55], [-26.80, 5.40, 13.55]], 1.65);   // J2
    color("#222222") lead([[0.00, 28.55, 29.50], [0.00, 29.08, 29.50], [0.00, 29.60, 29.50], [0.00, 30.13, 29.50], [0.00, 30.65, 29.50], [0.00, 30.65, 29.50], [-0.00, 31.15, 29.50], [-0.00, 31.15, 29.50], [-0.00, 31.64, 29.50], [-0.00, 31.64, 29.50], [-0.01, 32.14, 29.50], [-0.01, 32.14, 29.50], [-0.01, 32.63, 29.50], [-0.01, 32.63, 29.50], [-0.01, 33.12, 29.50], [-0.01, 33.12, 29.50], [-0.02, 33.62, 29.50], [-0.02, 33.62, 29.50], [-0.03, 34.11, 29.50], [-0.03, 34.11, 29.50], [-0.04, 34.61, 29.50], [-0.04, 34.61, 29.50], [-0.05, 35.10, 29.51], [-0.05, 35.10, 29.51], [-0.06, 35.59, 29.51], [-0.06, 35.59, 29.51], [-0.07, 36.09, 29.51], [-0.07, 36.09, 29.51], [-0.08, 36.58, 29.51], [-0.08, 36.58, 29.51], [-0.10, 37.07, 29.51], [-0.10, 37.07, 29.51], [-0.11, 37.57, 29.51], [-0.11, 37.57, 29.51], [-0.13, 38.06, 29.52], [-0.13, 38.06, 29.52], [-0.15, 38.55, 29.52], [-0.15, 38.55, 29.52], [-0.17, 39.05, 29.52], [-0.17, 39.05, 29.52], [-0.19, 39.54, 29.52], [-0.19, 39.54, 29.52], [-0.21, 40.04, 29.53], [-0.21, 40.04, 29.53], [-0.23, 40.53, 29.53], [-0.23, 40.53, 29.53], [-0.26, 41.02, 29.53], [-0.26, 41.02, 29.53], [-0.28, 41.52, 29.54], [-0.28, 41.52, 29.54], [-0.31, 42.01, 29.54], [-0.31, 42.01, 29.54], [-0.34, 42.50, 29.54], [-0.34, 42.50, 29.54], [-0.36, 42.99, 29.55], [-0.36, 42.99, 29.55], [-0.39, 43.49, 29.55], [-0.39, 43.49, 29.55], [-0.43, 43.98, 29.55], [-0.43, 43.98, 29.55], [-0.46, 44.47, 29.56], [-0.46, 44.47, 29.56], [-0.49, 44.97, 29.56], [-0.49, 44.97, 29.56], [-0.52, 45.46, 29.57], [-0.52, 45.46, 29.57], [-0.56, 45.95, 29.57], [-0.56, 45.95, 29.57], [-0.60, 46.44, 29.57], [-0.60, 46.44, 29.57], [-0.64, 46.94, 29.58], [-0.64, 46.94, 29.58], [-0.67, 47.43, 29.58], [-0.67, 47.43, 29.58], [-0.71, 47.92, 29.59], [-0.71, 47.92, 29.59], [-0.76, 48.41, 29.59], [-0.76, 48.41, 29.59], [-0.80, 48.90, 29.60], [-0.80, 48.90, 29.60], [-0.84, 49.40, 29.61], [-0.84, 49.40, 29.61], [-0.89, 49.89, 29.61], [-0.89, 49.89, 29.61], [-0.93, 50.38, 29.62], [-0.93, 50.38, 29.62], [-0.98, 50.87, 29.62], [-0.98, 50.87, 29.62], [-1.03, 51.36, 29.63], [-1.03, 51.36, 29.63], [-1.08, 51.85, 29.63], [-1.08, 51.85, 29.63], [-1.13, 52.35, 29.64], [-1.13, 52.35, 29.64], [-1.18, 52.84, 29.65], [-1.18, 52.84, 29.65], [-1.23, 53.33, 29.65], [-1.23, 53.33, 29.65], [-1.29, 53.82, 29.66], [-1.29, 53.82, 29.66], [-1.34, 54.31, 29.67], [-1.34, 54.31, 29.67], [-1.40, 54.80, 29.67], [-1.40, 54.80, 29.67], [-1.46, 55.29, 29.68], [-1.46, 55.29, 29.68], [-1.52, 55.78, 29.69], [-1.52, 55.78, 29.69], [-1.58, 56.27, 29.70], [-1.58, 56.27, 29.70], [-1.64, 56.76, 29.70], [-1.64, 56.76, 29.70], [-1.70, 57.25, 29.71], [-1.70, 57.25, 29.71], [-1.76, 57.74, 29.72], [-1.76, 57.74, 29.72], [-1.83, 58.23, 29.73], [-1.83, 58.23, 29.73], [-1.89, 58.72, 29.74], [-1.89, 58.72, 29.74], [-1.96, 59.21, 29.74], [-1.96, 59.21, 29.74], [-2.03, 59.71, 29.75], [-2.10, 60.21, 29.76], [-2.17, 60.71, 29.77], [-2.24, 61.21, 29.78], [-2.30, 61.71, 29.79], [-2.37, 62.20, 29.80], [-2.44, 62.70, 29.81], [-2.51, 63.20, 29.81], [-2.58, 63.70, 29.82], [-2.65, 64.20, 29.83], [-2.72, 64.70, 29.84], [-2.79, 65.20, 29.85], [-2.86, 65.70, 29.86], [-2.92, 66.20, 29.87], [-2.99, 66.70, 29.87], [-3.06, 67.20, 29.88], [-3.13, 67.70, 29.89], [-3.20, 68.20, 29.90], [-3.27, 68.70, 29.91], [-3.34, 69.20, 29.92], [-3.41, 69.70, 29.93], [-3.48, 70.20, 29.93], [-3.54, 70.70, 29.94], [-3.61, 71.19, 29.95], [-3.68, 71.69, 29.96], [-3.75, 72.19, 29.97], [-3.75, 72.19, 29.97], [-3.82, 72.64, 29.98], [-3.82, 72.64, 29.98], [-3.88, 73.09, 30.00], [-3.88, 73.09, 30.00], [-3.96, 73.54, 30.02], [-3.96, 73.54, 30.02], [-4.04, 73.99, 30.05], [-4.04, 73.99, 30.05], [-4.12, 74.44, 30.09], [-4.12, 74.44, 30.09], [-4.21, 74.88, 30.13], [-4.21, 74.88, 30.13], [-4.30, 75.32, 30.18], [-4.30, 75.32, 30.18], [-4.40, 75.76, 30.24], [-4.40, 75.76, 30.24], [-4.51, 76.26, 30.31], [-4.63, 76.77, 30.38], [-4.74, 77.27, 30.45], [-4.86, 77.77, 30.51], [-4.97, 78.27, 30.58], [-5.08, 78.77, 30.65], [-5.20, 79.27, 30.72], [-5.31, 79.77, 30.79], [-5.43, 80.28, 30.86], [-5.54, 80.78, 30.92], [-5.65, 81.28, 30.99], [-5.77, 81.78, 31.06], [-5.88, 82.28, 31.13], [-6.00, 82.78, 31.20], [-6.11, 83.28, 31.27], [-6.22, 83.79, 31.33], [-6.34, 84.29, 31.40], [-6.45, 84.79, 31.47], [-6.57, 85.29, 31.54], [-6.68, 85.79, 31.61], [-6.79, 86.29, 31.68], [-6.91, 86.79, 31.74], [-6.91, 86.79, 31.74], [-7.02, 87.27, 31.82], [-7.02, 87.27, 31.82], [-7.12, 87.75, 31.92], [-7.12, 87.75, 31.92], [-7.23, 88.22, 32.04], [-7.23, 88.22, 32.04], [-7.34, 88.69, 32.18], [-7.34, 88.69, 32.18], [-7.44, 89.15, 32.33], [-7.44, 89.15, 32.33], [-7.54, 89.60, 32.51], [-7.54, 89.60, 32.51], [-7.64, 90.04, 32.71], [-7.64, 90.04, 32.71], [-7.74, 90.48, 32.93], [-7.74, 90.48, 32.93], [-7.83, 90.91, 33.17], [-7.83, 90.91, 33.17], [-7.92, 91.32, 33.43], [-7.92, 91.32, 33.43], [-8.01, 91.73, 33.70], [-8.01, 91.73, 33.70], [-8.10, 92.12, 34.00], [-8.10, 92.12, 34.00], [-8.18, 92.50, 34.30], [-8.18, 92.50, 34.30], [-8.26, 92.87, 34.63], [-8.26, 92.87, 34.63], [-8.34, 93.22, 34.97], [-8.34, 93.22, 34.97], [-8.41, 93.56, 35.33], [-8.41, 93.56, 35.33], [-8.48, 93.88, 35.70], [-8.48, 93.88, 35.70], [-8.54, 94.19, 36.09], [-8.54, 94.19, 36.09], [-8.60, 94.48, 36.49], [-8.60, 94.48, 36.49], [-8.66, 94.75, 36.90], [-8.66, 94.75, 36.90], [-8.71, 95.01, 37.32], [-8.71, 95.01, 37.32], [-8.76, 95.25, 37.75], [-8.76, 95.25, 37.75], [-8.81, 95.47, 38.20], [-8.81, 95.47, 38.20], [-8.85, 95.67, 38.65], [-8.85, 95.67, 38.65], [-8.88, 95.85, 39.11], [-8.88, 95.85, 39.11], [-8.91, 96.01, 39.58], [-8.91, 96.01, 39.58], [-8.94, 96.15, 40.06], [-8.94, 96.15, 40.06], [-8.96, 96.28, 40.54], [-8.96, 96.28, 40.54], [-8.98, 96.38, 41.03], [-8.98, 96.38, 41.03], [-8.99, 96.46, 41.52], [-8.99, 96.46, 41.52], [-9.00, 96.52, 42.01], [-9.00, 96.52, 42.01], [-9.00, 96.56, 42.51], [-9.00, 96.56, 42.51], [-9.00, 96.56, 42.51], [-9.00, 96.56, 42.51], [-9.01, 96.59, 43.00], [-9.01, 96.59, 43.00], [-9.04, 96.62, 43.49], [-9.04,
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

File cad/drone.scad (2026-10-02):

//NAVCORE-SoOP - rudimentary assembly model

$fn = 48;                       //facet count; drop to 24 if preview is slow

//what to show
show_props     = true;
show_battery   = false;         //on by default it hides the whole stack
show_frame     = true;
show_top_plate = true;          //off for a plan view of the stack
show_camera    = false;         //DEFERRED OV9281 flow camera - competes for the belly slot
show_skids     = true;          //TPU landing skids at the motor pattern
//the PLUGGED-IN assembly (Stage 5): every edge connector drawn mated
show_plugs     = true;
show_cables    = true;          //every lead, as the cable check routes it
//false, because it does not fit and is not fitted
show_rec_cam   = true;         //XIAO ESP32S3 Sense on the nose, recording to microSD
show_pi        = false;         //Radxa Zero 3W companion - DEFERRED, does not fit here
explode        = 0;             //try 28 for an exploded view

//airframe
//GENERATED from tools/design.py by tools/gen_scad_frame.py
include <frame.scad>
//frame.scad is GENERATED from design.py and the real board
include <mounts.scad>
//plugs.scad is GENERATED from the board and design.MATING_FACE/MATING_CLEARANCE
include <plugs.scad>
//cables.scad is GENERATED by the cable check
include <cables.scad>

plate_t        = bottom_plate_t;   //the plate this model draws

//arm_w was 12 and commented "cosmetic: arm render width, no check uses it"
arm_w          = arm_plate_w;      //[M] 31.08 mm, from frame.scad

//z DATUMS
//the stack does not sit on the bottom plate
z_bot_plate = 0;
z_arm       = bottom_plate_t;                   //arms sit ON the bottom plate
z_mid_plate = z_arm + arm_t;                    //mid plate clamps the arms
z_stack     = z_mid_plate + medium_plate_t;     //ESC starts here
stack_h     = esc_pcb + esc_parts + gap + fc_bot_parts + fc_pcb + fc_top_parts;

//SETTLED by the DXF (design.TOP_PLATE_MOUNT)
top_plate_z    = standoff_len;                  //underside of the top plate, from frame.scad
fc_top_z       = z_stack + stack_h;      //top of the FC's tallest part
headroom       = top_plate_z - fc_top_z;

motor_off = wheelbase / 2 / sqrt(2);     //offset on each axis, square X

//rectangular, and a different rectangle per plate
stack_holes = [for (sx = [-1, 1], sy = [-1, 1]) [sx * hole_pitch/2, sy * hole_pitch/2]];
module plate(w, l, t, y_off, holes) {
    difference() {
        translate([0, y_off, 0])
            linear_extrude(t) offset(r = 4) square([w - 8, l - 8], center = true);
        //plate_hole_dia, not screw_dia
        for (h = holes)
            translate([h[0], h[1], -1]) cylinder(d = plate_hole_dia, h = t + 2);
    }
}

module arm() {
    hull() {
        cylinder(d = arm_w, h = arm_t);
        translate([motor_off * sqrt(2), 0, 0]) cylinder(d = arm_w, h = arm_t);
    }
}

module frame() {
    color("#22252a") {
        //bottom plate: press nuts at the stack pattern, rear posts stand on it
        translate([0, 0, z_bot_plate])
            plate(bot_plate_w, bot_plate_l, bottom_plate_t, plate_y_bottom,
                  concat(stack_holes, rear_posts));
        for (a = [45, 135, 225, 315])
            rotate([0, 0, a]) translate([0, 0, z_arm]) arm();
        //mid plate: the 48.50 x 106.59 strip that carries the stack
        translate([0, 0, z_mid_plate])
            plate(fc_plate_w, fc_plate_l, medium_plate_t, plate_y_fc,
                  concat(stack_holes, front_posts));
        //TOP PLATE. 42.50 x 160.26 - the long one, ABOVE the prop plane
        if (show_top_plate) translate([0, 0, top_plate_z])
            plate(top_plate_w, top_plate_l, upper_plate_t, plate_y_top,
                  concat(front_posts, rear_posts));
        //corner posts
        for (p = front_posts)
            translate([p[0], p[1], z_stack]) color("#8d949c") difference() {
                cylinder(d = post_od, h = standoff_front);
                translate([0, 0, -1]) cylinder(d = plate_hole_dia, h = standoff_front + 2);
            }
        for (p = rear_posts)
            translate([p[0], p[1], z_arm]) color("#8d949c") difference() {
                cylinder(d = post_od, h = standoff_rear);
                translate([0, 0, -1]) cylinder(d = plate_hole_dia, h = standoff_rear + 2);
            }
    }
}

module motors() {
    for (sx = [-1, 1], sy = [-1, 1])
        translate([sx * motor_off, sy * motor_off, z_arm + arm_t]) {
            color("#9aa3ab") cylinder(d = motor_dia, h = motor_h);
            color("#3a3f47") translate([0, 0, motor_h]) cylinder(d = 6, h = 4);
        }
}

module props() {
    for (sx = [-1, 1], sy = [-1, 1])
        translate([sx * motor_off, sy * motor_off, z_arm + arm_t + motor_h + 4])
            color("#2f3339", 0.30) cylinder(d = prop_dia, h = 1.2);
}

//ESC sits directly on the bottom plate, FC above it
esc_z = z_stack;
fc_z  = esc_z + esc_pcb + esc_parts + gap + fc_bot_parts + explode;

module esc() {
    translate([0, 0, esc_z + explode * 0.4]) {
        //with its 30.5 mm mounting holes
        color("#2b3037") difference() {
            linear_extrude(esc_pcb)
                offset(r = 2) square([esc_l - 4, esc_w - 4], center = true);
            for (sx = [-1, 1], sy = [-1, 1])
                translate([sx * hole_pitch/2, sy * hole_pitch/2, -1])
                    cylinder(d = hole_dia, h = esc_pcb + 2);
        }
        color("#3d444d") translate([0, 0, esc_pcb]) difference() {
            linear_extrude(esc_parts)
                offset(r = 2) square([esc_l - 12, esc_w - 12], center = true);
            for (sx = [-1, 1], sy = [-1, 1])
                translate([sx * hole_pitch/2, sy * hole_pitch/2, -1])
                    cylinder(d = grommet_dia, h = esc_parts + 2);
        }
    }
}

module fc() {
    translate([0, 0, fc_z]) {
        //PCB
        color("#1e4a3c") difference() {
            linear_extrude(fc_pcb) offset(r = 2) square([fc_l - 4, fc_w - 4], center = true);
            for (sx = [-1, 1], sy = [-1, 1])
                translate([sx * hole_pitch/2, sy * hole_pitch/2, -1])
                    cylinder(d = hole_dia, h = fc_pcb + 2);
        }
        //component envelope, top and bottom - a blob, not real parts
        color("#14332a") translate([0, 0, fc_pcb]) difference() {
            linear_extrude(fc_top_parts) offset(r = 1)
                square([fc_l - 14, fc_w - 14], center = true);
            for (sx = [-1, 1], sy = [-1, 1])
                translate([sx * hole_pitch/2, sy * hole_pitch/2, -1])
                    cylinder(d = grommet_dia, h = fc_top_parts + 2);
        }
        color("#14332a") translate([0, 0, -fc_bot_parts]) difference() {
            linear_extrude(fc_bot_parts) offset(r = 1)
                square([fc_l - 16, fc_w - 16], center = true);
            for (sx = [-1, 1], sy = [-1, 1])
                translate([sx * hole_pitch/2, sy * hole_pitch/2, -1])
                    cylinder(d = grommet_dia, h = fc_bot_parts + 2);
        }
        //USB-C, at the board edge [M] 0.80 mm inboard
        color("#b8bcc2")
            translate([0, fc_w/2 - 4.2, fc_pcb]) cube([9, 8, 3.2], center = false);
    }
}

module stack_screws() {
    //FROM the MID plate UP, not from z = 0
    m3_nut_h = 2.4;
    for (sx = [-1, 1], sy = [-1, 1])
        translate([sx * hole_pitch/2, sy * hole_pitch/2, z_mid_plate])
            color("#c0c5cb")
                cylinder(d = screw_dia, h = fc_z + fc_pcb + m3_nut_h - z_mid_plate);
}

module battery() {
    //long axis fore-and-aft, along the top plate
    translate([0, batt_y, top_plate_z + upper_plate_t + batt_h/2])
        color("#5a2f2f", 0.35) cube([batt_w, batt_l, batt_h], center = true);
}

//flow camera module [A] 12 mm deep

module camera() {
    //hangs UNDER the BOTTOM plate, lens pointing straight down
    translate([0, 0, -cam_mod_t]) {
        color("#20242a") linear_extrude(cam_mod_t)
            offset(r = 1) square([cam_mod_w, cam_mod_w], center = true);
        //lens barrel poking out of the module bottom (3.5 mm, per design.CAMERA.lens_len)
        color("#0d0f11") translate([0, 0, -3.5]) cylinder(d = 8, h = 3.5);
    }
}

//skid() and skids() are generated into mounts.scad from design.SKID (tools/gen_scad_mounts.py)

//Radxa Zero 3W companion [D] 65 x 30
//Radxa publishes 65 x 30 mm and NOTHING about the mounting holes
pi_hole_dia  = 2.75;            //[U] diameter assumed; pattern unpublished
pi_y_off = 25;

module pi() {
    //pi on the top plate, long axis along X
    translate([0, pi_y_off, top_plate_z + plate_t]) {
        color("#1a7a4a") linear_extrude(pi_t)
            offset(r = 1) square([pi_l, pi_w], center = true);
        //NO mounting posts: Radxa does not publish the hole pattern
    }
}
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

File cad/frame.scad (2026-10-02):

// GENERATED by tools/gen_scad_frame.py - DO NOT EDIT.
// Every value comes from tools/design.py, which is the single source of truth for the
// airframe. Edit it there and regenerate, or the model and the checks drift apart again.
//
// frame : [D] github.com/tbs-trappy/source_one So1-V6-7inDC-2025-JUL-07.dxf, stack patterns parsed directly 2026-09-02; [L] hobbyrc.co.uk for standoffs 30/22 mm, plates and 143.5 g; [A] plate outline 200x230 mm - overall footprint only, not load-bearing on any check
// motor : [D] 41 g, M3 19x19, M5 prop adapter thread, 12N14P (BrotherHobby Avenger product data); [A] 1250 g thrust; [D] 28 mm body from the 2806.5 stator designation, [A] 15 mm bell height
// plates: [D] tools/parse_frame_dxf.py -> cad/frame-dxf.json from So1-V6-7inDC-2025-JUL-07.dxf (sha 398556cd); re-derivable, not a one-off flatten
// batt  : [L] retailer listing
// prop  : [D] Gemfan Flash 7040-3 published spec: 5 mm centre hole, 178.43 mm disc, 7.9 g, PC. Bore matches the [D] M5 motor shaft. A different brand of 7040 may differ in mass; the 5 mm bore is universal for 7in

wheelbase      = 320.0;
frame_size_x   = 200.0;
frame_size_y   = 230.0;
inner_h        = 25.0;
bottom_plate_t = 2.5;
medium_plate_t = 2.0;
upper_plate_t  = 2.0;
arm_t          = 6.0;
cam_plate_t    = 2.0;

motor_dia      = 28.0;
motor_h        = 15.0;
prop_dia       = 178.4;

batt_l = 138; batt_w = 47; batt_h = 48;
batt_y = -6.0;   // forward of centre, so the rear posts stay free

// ---- PLATE OUTLINES, PARSED FROM THE MANUFACTURER DXF ---------------------
// drone.scad drew ALL THREE plates as one 50 mm square, from a variable whose own
// comment called it a placeholder ("must be >= fc_w = 46.10"). Every frame-vs-anything
// clearance the CAD fit check reported was therefore measured against an airframe that
// does not exist - and the error was not small or in the safe direction: the real top
// plate is 160.26 mm long, more than three times the placeholder, reaching 80 mm out
// under a prop disc of 89.2 mm radius.
//
// These are [M], flattened from So1-V6-7inDC-2025-JUL-07.dxf. The three plates are
// genuinely different shapes and the model now says so.
fc_plate_w     = 48.5;    // the mid plate: carries the 30.5 mm stack pattern
fc_plate_l     = 106.59;
top_plate_w    = 42.5;    // carries the battery - and the battery OVERHANGS it
top_plate_l    = 160.26;
bot_plate_w    = 48.5;
bot_plate_l    = 107.62;
arm_plate_w    = 31.08;   // widest point of an arm, at the motor end
arm_plate_l    = 185.21;
batt_overhang  = 2.25;   // per side, battery vs top plate

// ---- STACK HEIGHTS, MEASURED FROM THE BOARD -------------------------------
// NOT hardcoded. drone.scad carried fc_bot_parts = 2.50 while design.stack_heights()
// measured 3.00 on the real board (L5, the 10 uH inductor) - so the model showed
// 0.5 mm MORE clearance to the ESC than exists. Three copies of this number have
// already disagreed once in this project (2.5 / 2.3 / 3.0); this is the fourth, and
// it is now generated so it cannot be the fifth.
fc_l           = 46.60;   // Edge.Cuts bbox - conservative
fc_w           = 47.30;
fc_l_fab       = 46.50;   // centreline: what JLC routes to
fc_w_fab       = 47.20;
fc_pcb         = 1.60;
fc_top_parts   = 4.4;          // tallest: J3
fc_bot_parts   = 4.4;          // tallest: J14

esc_l          = 45.6;
esc_w          = 44.0;
esc_pcb        = 1.6;
esc_parts      = 6.2;

skid_t          = 3.5;
cam_drop        = 45.0;

skid_hole_pitch = 19.0;
gap             = 3.0;    // compressed grommet - [A], re-measure on assembly
grommet_dia     = 6.0;
hole_pitch      = 30.5;
hole_dia        = 4.0;
plate_hole_dia  = 3.2;   // M3 close clearance, > screw_dia
screw_dia       = 3.0;     // M3

// TOP PLATE HEIGHT (design.TOP_PLATE_MOUNT). The DXF settles the arrangement: the front
// standoffs stand on the MID plate, the rear ones on the BOTTOM plate, 8 mm lower, so one
// flat top plate needs rear = front + 8 (25 + 8 = 33).
// standoff_len is the top plate's underside above z = 0 (bottom of the bottom plate).
standoff_len    = 35.5;   // = bottom_t + 33 = mid plate top + 25
standoff_front  = 25.0;
standoff_rear   = 33.0;
post_od         = 5.0;
front_posts     = [[-14.6, -27.88], [14.6, -27.88], [-14.6, -52.88], [14.6, -52.88]];   // on the mid plate, rel. stack centre
rear_posts      = [[-14.6, 27.88], [14.6, 27.88], [-11.0, 80.75], [11.0, 80.75]];   // on the bottom plate
plate_y_fc      = -29.16;    // plate centres rel. the stack centre, +y aft
plate_y_bottom  = 31.09;
plate_y_top     = 4.78;
standoff_need   = 31.7;   // stack top above z = 0
standoff_slack  = 3.8;  // headroom under the top plate
cam_mod_t       = 12.0;
cam_mod_w       = 30.0;
pi_l            = 65.0;
pi_w            = 30.0;
pi_t            = 1.2;

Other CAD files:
cad/mounts.scad
cad/plugs.scad

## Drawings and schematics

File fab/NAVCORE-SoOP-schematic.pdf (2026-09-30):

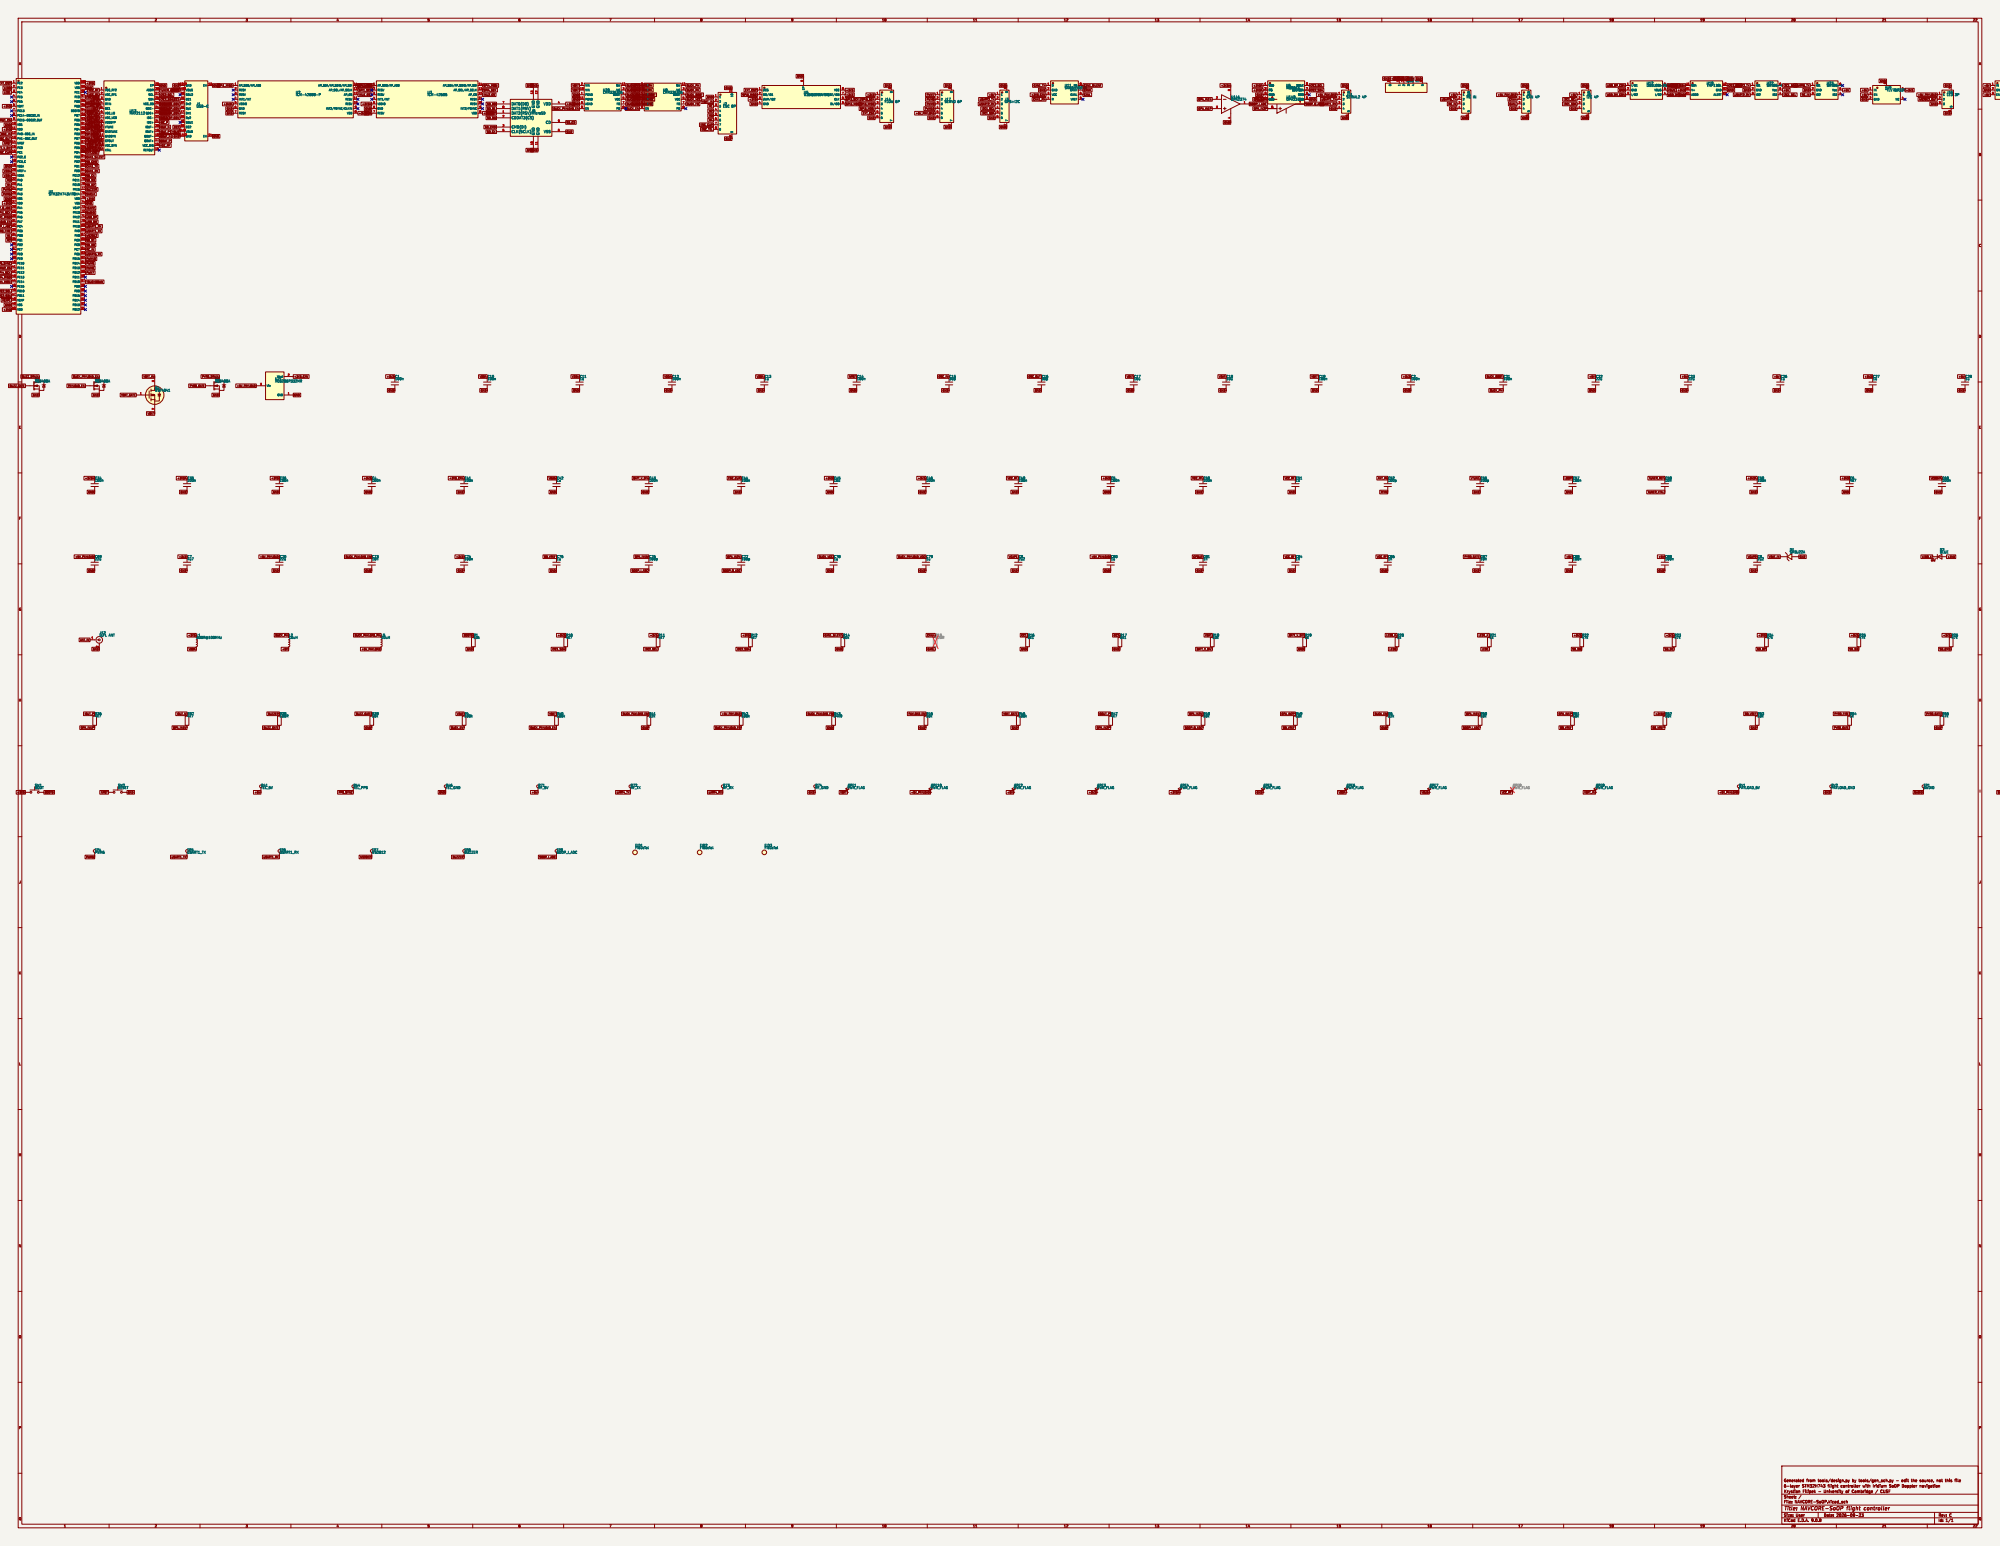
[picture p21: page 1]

VDD 100 VSS 99 PE1 98 PE0 97 PB9 96 PB8 95 BOOT0 94 PB7 93 PB6 92 PB5 91 PB4 90 PB3 89 PD7 88 PD6 87 PD5 86 PD4 85 PD3 84 PD2 83 PD1 82 PD0 81 PC12 80 PC11 79 PC10 78 PA15 77 PA14 76 VDD 75 VSS 74 VCAP 73 PA13 72 PA12 71 PA11 70 PA10 69 PA9 68 PA8 67 PC9 66 PC8 65 PC7 64 PC6 63 PD15 62 PD14 61 PD13 60 PD12 59 PD11 58 PD10 57 PD9 56 PD8 55 PB15 54 PB14 53 PB13 52 PB12 51 U1STM32H743VIT6

PE2 1 PE3 2 PE4 3 PE5 4 PE6 5 VBAT 6 PC13 7 PC14-OSC32_IN 8 PC15-OSC32_OUT 9 VSS 10 VDD 11 PH0-OSC_IN 12 PH1-OSC_OUT 13 NRST 14 PC0 15 PC1 16 PC2_C 17 PC3_C 18 VSSA 19 VREF+ 20 VDDA 21 PA0 22 PA1 23 PA2 24 PA3 25 VSS 26 VDD 27 PA4 28 PA5 29 PA6 30 PA7 31 PC4 32 PC5 33 PB0 34 PB1 35 PB2 36 PE7 37 PE8 38 PE9 39 PE10 40 PE11 41 PE12 42 PE13 43 PE14 44 PE15 45 PB10 46 PB11 47 VCAP 48 VSS 49 VDD 50

IOUT+ 19 QOUT- 18 QOUT+ 17 VCC_DIG 16 REFOUT 15 U13 MAX2112
I2C1_SCL EXT_CS1 USART2_TX USART2_RX CPOUT VCC_RF
SPI3_MOSI VCOBYP CAN1_SILENT

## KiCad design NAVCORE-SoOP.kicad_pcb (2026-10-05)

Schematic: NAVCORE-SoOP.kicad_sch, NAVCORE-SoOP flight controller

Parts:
C1, C2, C3, C4, C5, C10, C12, C14, C21, C30, C31, C32, C33, C34, C35, C36, C41, C43, C44, C46, C49, C50, C57, C59, C60, C65, C68, C74, C88, C89, C90, C94, C95, C96: 100n; C_0402_1005Metric; LCSC C1525
C6, C7: 4u7; C_0805_2012Metric; LCSC C354262
C8, C9, C29: 2u2; C_0402_1005Metric; LCSC C12530
C11, C13, C26, C27, C28, C51, C67, C75, C78, C79, C80: 1u; C_0402_1005Metric; LCSC C52923
C15, C16: 30p; C_0402_1005Metric; LCSC C107004
C17, C18: 10u; C_1206_3216Metric; LCSC C13585
C19, C66: 100n; C_0402_1005Metric; LCSC C131394
C22, C23, C69, C70, C92: 22u; C_1206_3216Metric; LCSC C5177178
C42: 1u; C_0805_2012Metric; LCSC C91185
C45, C93: 10u; C_0805_2012Metric; LCSC C1713
C52, C56, C76, C77: 100p; C_0402_1005Metric; LCSC C1546
C58, C73: 10n; C_0402_1005Metric; LCSC C15195
C61, C63: 47n; C_0402_1005Metric; LCSC C82219
C81, C84, C86: 1n; C_0402_1005Metric; LCSC C1523
C91: 10p; C_0402_1005Metric; LCSC C32949
D1: SMBJ22A; SMB_L4.6-W3.6-LS5.3-RD; LCSC C113993
D2: BLUE; LED_0603_1608Metric; LCSC C965807
D3: GREEN; LED_0603_1608Metric; LCSC C965804
D4: 1N4148W; SOD-123F_L2.7-W1.6-LS3.8-RD; LCSC C81598
D6: PESD2CANFD24LT; SOT-23-3_L2.9-W1.6-P1.90-LS2.8-BR; LCSC C6952426
D7, D9: PESD5V0C1BSF; DSN0603-2_L0.6-W0.3-P0.40-BI; LCSC C477955
D8: PTVS5V0S1UR; SOD-123FL_L2.7-W1.8-LS3.8-RD; LCSC C5380694
DZ1: BZT52C15; SOD-123_L2.7-W1.6-LS3.7-RD; LCSC C173427
D_USB: B5819W; SOD-123_L2.7-W1.6-LS3.7-RD-1; LCSC C8598
FID1, FID2, FID3: Fiducial; Fiducial_1mm_Mask2mm
J1: USB-C; USB-C-SMD_TYPE-C-16PIN-2MD-073; LCSC C2765186
J2: ESC 8P; CONN-SMD_SM08B-GHS-TB-LF-SN; LCSC C42376901
J3: GPS+I2C; CONN-SMD_XY-SM06B-GHS-TB; LCSC C51940119
J5: RC IN; CONN-SMD_4P-P1.25_BX-GH1.25-4PWT; LCSC C18077720
J6: CAN 4P; CONN-SMD_4P-P1.25_BX-GH1.25-4PWT; LCSC C18077720
J8: microSD; TF-SMD_TF-01A; LCSC C91145
J9: I2C 4P; CONN-SMD_4P-P1.25_BX-GH1.25-4PWT; LCSC C18077720
J11: SERIAL2 4P; CONN-SMD_4P-P1.25_BX-GH1.25-4PWT; LCSC C18077720
J12: MMCX-KWE-90; MMCX-TH_DL-MMCX-KWE-90; LCSC C2894793
J14: FLOW 6P; CONN-SMD_XY-SM06B-GHS-TB; LCSC C51940119
J17: SERVO1; HDR-SMD_3P-P2.54-H-M_KH-2.54PH-1X3P-L13.5-WT; LCSC C20610212
J19: TC2030-NL; Tag-Connect_TC2030-IDC-NL_2x03_P1.27mm_Vertical
J21: COMPANION; CONN-SMD_XY-SM06B-GHS-TB; LCSC C51940119
J22: PAYLOAD 5V; CONN-TH_SM03B-GHS-TB-LF-SN; LCSC C514175
J23: SERVO2; HDR-SMD_3P-P2.54-H-M_KH-2.54PH-1X3P-L13.5-WT; LCSC C20610212
L1: 600R@100MHz; L_0805_2012Metric; LCSC C18305
L2: 10uH; L_APV_ANR4030; LCSC C167879
L5: 10uH; L_APV_ANR5040; LCSC C354610
L6: 27nH; L0402; LCSC C113111
P151: LED_5V; TestPoint_Pad_1.5x1.5mm
P152: LED_DIN; TestPoint_Pad_1.5x1.5mm
P153: LED_GND; TestPoint_Pad_1.5x1.5mm
P161: BUZ_5V; TestPoint_Pad_1.5x1.5mm
P162: BUZ_OUT; TestPoint_Pad_1.5x1.5mm
P163: BUZ_GND; TestPoint_Pad_1.5x1.5mm
PF1, PF2, PF3, PF4, PF5, PF6, PF7, PF9, PF10: PWR_FLAG
PF8: PWR_FLAG; not fitted
Q1, Q3: AO3400A; SOT-23-3_L2.9-W1.3-P1.90-LS2.4-BR; LCSC C20917
Q4: WST4041; SOT-23-3_L2.9-W1.3-P1.90-LS2.4-BR; LCSC C148357
R1, R14, R39, R45, R48, R49, R50, R51, R52, R53, R59, R60: 10k; R_0402_1005Metric; LCSC C25744
R4, R6, R40, R42, R46: 100k; R_0402_1005Metric; LCSC C25741
R5, R41: 22k; R_0402_1005Metric; LCSC C25767
R7, R43: 24k9; R_0402_1005Metric; LCSC C25874
R9, R10, R11, R12, R31, R36, R37, R47, R58: 4k7; R_0402_1005Metric; LCSC C25900
R15: 120R; R_0402_1005Metric; LCSC C25862; not fitted
R16, R17: 5k1; R_0402_1005Metric; LCSC C25905
R18: 10k; R_0603_1608Metric; LCSC C25804
R19, R20, R21, R35: 1k; R_0402_1005Metric; LCSC C11702
R22, R23, R24, R25, R26, R27: 47k; R_0402_1005Metric; LCSC C25792
R28, R29: 0R; R_0402_1005Metric; LCSC C17168
R34: 330R; R_0402_1005Metric; LCSC C25104
R38, R70, R72, R73, R74, R75: 100R; R_0402_1005Metric; LCSC C25076
R57: 470R; R_0402_1005Metric; LCSC C25117
R61: 210k; R_0402_1005Metric; LCSC C58827
R62: 2R2; R_0402_1005Metric; LCSC C25101
R71: 2k2; R_0402_1005Metric; LCSC C25879
RN1: 33R x4; R_Array_Convex_4x0402; LCSC C25501
SW1: BOOT; SW_SPST_B3U-1000P; LCSC C231329
SW2: RESET; SW_SPST_B3U-1000P; LCSC C231329
TP3: PWM5; TestPoint_Pad_1.5x1.5mm
TP4: PWM6; TestPoint_Pad_1.5x1.5mm
TP9: SOOP_I_ADC; TestPoint_Pad_1.5x1.5mm
TP10: SOOP_Q_ADC; TestPoint_Pad_1.5x1.5mm
U1: STM32H743VIT6; LQFP-100_L14.0-W14.0-P0.50-LS16.0-BL; LCSC C5271084
U2: ICM-42688-P; LGA-14_L3.0-W2.5-P0.50-TL; LCSC C1850418
U3: ICM-42605; LGA-14_L3.0-W2.5-P0.50-TL; LCSC C2655099
U4: MS5611; SENSORS-SMD_MS5611-01BA03; LCSC C15639
U5: W25Q128JVPIQ; WSON-8-1EP_6x5mm_P1.27mm_EP3.4x4.3mm; LCSC C190862
U8, U20: LMR33630A; VQFN-12_L3.0-W2.0-P0.65-BL_TI_RNX; LCSC C2861505
U9: TLV75733P; SOT-23-5_L2.9-W1.6-P0.95-LS2.8-BL-EP; LCSC C22399950
U10: TLV75533; SOT-23-5_L3.0-W1.7-P0.95-LS2.8-BR; LCSC C404027
U11: SN65HVD230; SOIC-8_L4.9-W3.9-P1.27-LS6.0-BL; LCSC C12084
U12: USBLC6-2SC6; SOT-23-6_L2.9-W1.6-P0.95-LS2.8-BL; LCSC C2687116
U13: MAX2112; TQFN-28_L5.0-W5.0-P0.50-BL-EP3.3; LCSC C596391
U14: OPA2374; SOP-8_L4.9-W3.9-P1.27-LS6.0-BL; LCSC C444392
U17: 74LVC1G17; SOT-23-5_L3.0-W1.7-P0.95-LS2.8-BR; LCSC C7836
U19: TMP119; DSBGA-6_L1.5-W1.0-R2-C3-P0.40-BL; LCSC C22428347
U21: XC6206P332MR; SOT-23-3_L2.9-W1.6-P1.90-LS2.8-BR; LCSC C5446
U22, U23: SRV05-4; SOT-23-6_L2.9-W1.6-P0.95-LS2.8-BR; LCSC C6454456
U24: AP22653; SOT-23-6_L2.9-W1.6-P0.95-LS2.8-BR; LCSC C2158037
U25: INA180A2; SOT-23-5_L3.0-W1.7-P0.95-LS2.8-BL; LCSC C192764
U26, U27, U28, U29, U30: TPD4E05U06; USON-10_2.5x1.0mm_P0.5mm; LCSC C138714
Y1: 8MHz; CRYSTAL-SMD_4P-L3.2-W2.5-BL; LCSC C2682774
Y2: 25MHz TCXO; OSC-SMD_4P-L3.2-W2.5-BL; LCSC C5563878

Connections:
+3V3: C1.1, C2.1, C3.1, C4.1, C5.1, C6.1, C7.1, C27.1, C36.1, C45.1, C46.1, C74.1, C94.1, D2.2 (A), D3.2 (A), J8.4 (VDD), J14.1, J19.1, L1.1, PF3.1, R9.1, R10.1, R11.1, R12.1, R22.1, R23.1, R24.1, R25.1, R26.1, R27.1, R60.1, SW1.1, U1.6 (VBAT), U1.11 (VDD), U1.27 (VDD), U1.50 (VDD), U1.75 (VDD), U1.100 (VDD), U5.3 (#WP/IO2), U5.7 (#HOLD-OR-#REST/IO3), U5.8 (VCC), U9.5 (OUT), U19.B1 (V+), U25.5 (VS)
+3V3A: C29.1, C30.1, C31.1, C32.1, C33.1, C34.1, C35.1, C59.1, PF4.1, R28.1, R52.1, U2.5 (VDDIO), U2.8 (VDD), U3.5 (VDDIO), U3.8 (VDD), U4.1 (VDD), U4.2 (PS), U10.5 (OUT), U14.8 (VCC+), Y2.4 (VCC)
+3V3_CAN: C41.1, C67.1, U11.3 (VCC), U21.2 (Vout)
+5V: C22.1, C23.1, C26.1, C28.1, C65.1, C88.1, C89.1, C95.1, D4.1 (K), D_USB.1 (-), J3.1, J5.1, J9.1, J21.1, L2.2, P161.1, PF2.1, R6.1, R59.1, U9.1 (IN), U9.3 (EN), U10.1 (IN), U10.3 (EN), U17.5 (VCC), U22.5 (Vcc), U23.5 (Vcc), U24.1 (IN)
+5V_BIAS: C90.1, C91.1, C93.1, L6.1, R62.2, U25.4 (IN-)
+5V_BIAS_SW: C96.1, R62.1, U24.6 (OUT), U25.3 (IN+)
+5V_PAYLOAD: C69.1, C70.1, C80.1, C92.1, D8.1 (K), J6.1, J11.1, J17.2, J22.1, J23.2, L5.2, P151.1, PF10.1, R42.1, U21.3 (Vin)
ANT_CURRENT: U1.17 (PC2_C), U25.1 (OUT)
ANT_IN: C52.1, D7.1 (A1), J12.1 (SIG), L6.2
BATT_V_DIV: C43.1, R18.2, R19.1, U1.15 (PC0)
BB_VREF: C75.1, R49.2, R51.2, R52.2, R53.1
BIAS_EN: R59.2, U1.33 (PC5), U24.3 (EN/EN#)
BIAS_FAULT: R60.2, U1.57 (PD10), U24.4 (FAULT#)
BIAS_ILIM: R61.1, U24.5 (ILIM)
BOOT0: R1.1, SW1.2, U1.94 (BOOT0)
BUCK_BOOT: C21.1, U8.4 (BOOT)
BUCK_EN: R4.2, R5.1, U8.9 (EN)
BUCK_FB: R6.2, R7.1, U8.7 (FB)
BUCK_PAYLOAD_BOOT: C68.1, U20.4 (BOOT)
BUCK_PAYLOAD_EN: C73.1, Q3.3 (D), R40.2, R41.1, U20.9 (EN)
BUCK_PAYLOAD_FB: R42.2, R43.1, U20.7 (FB)
BUCK_PAYLOAD_PH: C68.2, L5.1, U20.3 (NC), U20.12 (SW)
BUCK_PAYLOAD_VCC: C79.1, U20.5 (VCC)
BUCK_PH: C21.2, L2.1, U8.3 (NC), U8.12 (SW)
BUCK_VCC: C78.1, U8.5 (VCC)
BUZZER: R38.1, U1.77 (PA15)
BUZZ_DRAIN: D4.2 (A), P162.1, Q1.3 (D)
BUZZ_GATE: Q1.1 (G), R38.2, R39.1
CAN1_RX: U1.81 (PD0), U11.4 (R)
CAN1_SILENT: R14.1, U1.84 (PD3), U11.8 (RS)
CAN1_TX: U1.82 (PD1), U11.1 (D)
CANH: D6.1 (C), J6.2, R15.1, U11.7 (CANH)
CANL: D6.2 (C), J6.3, R15.2, U11.6 (CANL)
CC1: J1.A5 (CC1), R16.1
CC2: J1.B5 (CC2), R17.1
CPOUT: C81.1, R34.1, R57.1, U13.12 (CPOUT)
ESC_CUR: C44.1, R71.2, U1.16 (PC1)
ESC_CUR_J: J2.7, R71.1, U27.1 (D1+), U27.10 (NC)
ESC_TEL: R70.2, U1.97 (PE0)
ESC_TEL_J: J2.8, R70.1, U27.2 (D1-), U27.9 (NC)
EXT_CS1: J14.5, U1.7 (PC13), U29.5 (D2-), U29.6 (NC)
EXT_CS2: U1.1 (PE2), U5.1 (#CS)
GC1: R35.2, R58.2, U13.5 (GC1)
GND: C1.2, C2.2, C3.2, C4.2, C5.2, C6.2, C7.2, C8.2, C9.2, C10.2, C11.2, C12.2, C13.2, C14.2, C15.2, C16.2, C17.2, C18.2, C19.2, C22.2, C23.2, C26.2, C27.2, C28.2, C29.2, C30.2, C31.2, C32.2, C33.2, C34.2, C35.2, C36.2, C41.2, C42.2, C43.2, C44.2, C45.2, C46.2, C49.2, C50.2, C51.2, C56.2, C57.2, C59.2, C60.2, C65.2, C66.2, C67.2, C69.2, C70.2, C73.2, C74.2, C75.2, C78.2, C79.2, C80.2, C81.2, C84.2, C86.2, C88.2, C89.2, C90.2, C91.2, C92.2, C93.2, C94.2, C95.2, C96.2, D1.2 (A), D6.3 (A), D7.2 (A2), D8.2 (A), D9.2 (A2), J1.13 (EH), J1.14 (EH), J1.A1B12 (GND), J1.B1A12 (GND), J2.1, J2.9, J2.10, J3.6, J3.7, J3.8, J5.4, J5.5, J5.6, J6.4, J6.5, J6.6, J8.6 (VSS), J8.10 (GND), J8.11 (GND), J8.12 (GND), J8.13 (GND), J9.4, J9.5, J9.6, J11.4, J11.5, J11.6, J12.2 (GND), J12.3 (GND), J12.4 (GND), J12.5 (GND), J14.6, J14.7, J14.8, J17.3, J19.5, J19.6, J21.6, J21.7, J21.8, J22.2, J22.3, J22.4, J22.5, J23.3, P153.1, P163.1, PF5.1, Q1.2 (S), Q3.2 (S), R1.2, R5.2, R7.2, R14.2, R16.2, R17.2, R19.2, R29.1, R35.1, R39.2, R41.2, R43.2, R45.2, R46.2, R53.2, R61.2, SW2.2, U1.10 (VSS), U1.19 (VSSA), U1.26 (VSS), U1.49 (VSS), U1.74 (VSS), U1.99 (VSS), U2.6 (GND), U2.7 (RESV), U3.6 (GND), U3.7 (RESV), U4.3 (GND), U4.4 (CSB), U4.5 (CSB), U5.4 (GND), U5.9 (EP), U8.1 (PGND), U8.6 (AGND), U8.11 (PGND), U9.2 (GND), U9.6 (EP), U10.2 (GND), U11.2 (GND), U12.2 (GND), U13.3 (GND), U13.10 (GNDTUNE), U13.11 (GNDSYN), U13.29 (EP), U14.4 (VCC-), U17.3 (GND), U19.B2 (GND), U19.C1 (ADD0), U20.1 (PGND), U20.6 (AGND), U20.11 (PGND), U21.1 (GND), U22.2 (GND), U23.2 (GND), U24.2 (GND), U25.2 (GND), U26.3 (GND), U26.8 (GND), U27.3 (GND), U27.8 (GND), U28.3 (GND), U28.8 (GND), U29.3 (GND), U29.8 (GND), U30.3 (GND), U30.8 (GND), Y1.2 (GND), Y1.4 (GND), Y2.1 (GND or N.C.), Y2.2 (GND)
I2C1_SCL: J3.4, J9.2, R9.2, U1.92 (PB6), U19.A2 (SCL), U22.4 (IO3)
I2C1_SDA: J3.5, J9.3, R10.2, U1.93 (PB7), U19.A1 (SDA), U22.6 (IO4)
I2C2_SCL: R11.2, U1.46 (PB10), U4.8 (SCLK), U13.27 (SCL)
I2C2_SDA: R12.2, U1.47 (PB11), U4.7 (SDI/SDA), U13.26 (SDA)
IDC_N: C61.2, U13.22 (IDC-)
IDC_P: C61.1, U13.21 (IDC+)
IMU1_CS: U1.9 (PC15-OSC32_OUT), U2.12 (AP_CS)
IMU2_CS: U1.41 (PE11), U3.12 (AP_CS)
IOUT_N: R37.1, U13.20 (IOUT-)
IOUT_P: R36.1, U13.19 (IOUT+)
LED0: R20.2, U1.2 (PE3)
LED0_K: D2.1 (K), R20.1
LED1: R21.2, U1.3 (PE4)
LED1_K: D3.1 (K), R21.1
LOOP: C57.1, R34.2
M1: RN1.4 (R4.1), U1.34 (PB0)
M1_J: J2.3, RN1.5 (R4.2), U26.1 (D1+), U26.10 (NC)
M2: RN1.3 (R3.1), U1.35 (PB1)
M2_J: J2.4, RN1.6 (R3.2), U26.2 (D1-), U26.9 (NC)
M3: RN1.2 (R2.1), U1.22 (PA0)
M3_J: J2.5, RN1.7 (R2.2), U26.4 (D2+), U26.7 (NC)
M4: RN1.1 (R1.1), U1.23 (PA1)
M4_J: J2.6, RN1.8 (R1.2), U26.5 (D2-), U26.6 (NC)
NRST: C14.1, J19.3, SW2.1, U1.14 (NRST)
OPA_IN1N: C76.1, R37.2, R50.1, U14.2 (IN1-)
OPA_IN1P: R36.2, R51.1, U14.3 (IN1+)
OPA_IN2N: C77.1, R31.2, R48.1, U14.6 (IN2-)
OPA_IN2P: R47.2, R49.1, U14.5 (IN2+)
OSC_IN: C15.1, U1.12 (PH0-OSC_IN), Y1.1
OSC_OUT: C16.1, U1.13 (PH1-OSC_OUT), Y1.3
PAYLOAD_EN: Q3.1 (G), R45.1, U1.31 (PA7)
PWM5: TP3.1, U1.96 (PB9)
PWM6: TP4.1, U1.25 (PA3)
PWM7: R75.2, U1.95 (PB8)
PWM7_J: D9.1 (A1), J17.1, R75.1
PWM8: R74.2, U1.60 (PD13)
PWM8_J: J23.1, R74.1, U30.4 (D2+), U30.7 (NC)
QDC_N: C63.2, U13.24 (QDC-)
QDC_P: C63.1, U13.23 (QDC+)
QOUT_N: R31.1, U13.18 (QOUT-)
QOUT_P: R47.1, U13.17 (QOUT+)
RC_IN: J5.3, U1.64 (PC7), U23.3 (IO2)
RFIN: C52.2, U13.4 (RFIN)
SD_CD: J8.9 (CD), R27.2
SD_CK: J8.5 (CLK(SCLK)), U1.80 (PC12)
SD_CMD: J8.3 (CMD(DI)), R26.2, U1.83 (PD2)
SD_D0: J8.7 (DAT0(D0)), R22.2, U1.65 (PC8)
SD_D1: J8.8 (DAT1(RSV)), R23.2, U1.66 (PC9)
SD_D2: J8.1 (DAT2(RSV)), R24.2, U1.78 (PC10)
SD_D3: J8.2 (CDDAT3(CS)), R25.2, U1.79 (PC11)
SOOP_I_ADC: C76.2, R50.2, TP9.1, U1.32 (PC4), U14.1 (OUT1)
SOOP_Q_ADC: C77.2, R48.2, TP10.1, U1.28 (PA4), U14.7 (OUT2)
SPI1_MISO: U1.30 (PA6), U2.1 (AP_SDO/AP_AD0)
SPI1_MOSI: U1.88 (PD7), U2.14 (AP_SDA/AP_SDIO/AP_SDI)
SPI1_SCK: U1.29 (PA5), U2.13 (AP_SCL/AP_SCLK)
SPI3_MISO: J14.3, U1.90 (PB4), U5.2 (DO/IO1), U29.2 (D1-), U29.9 (NC)
SPI3_MOSI: J14.4, U1.91 (PB5), U5.5 (DI/IO0), U29.4 (D2+), U29.7 (NC)
SPI3_SCK: J14.2, U1.89 (PB3), U5.6 (CLK), U29.1 (D1+), U29.10 (NC)
SPI4_MISO: U1.43 (PE13), U3.1 (AP_SDO/AP_AD0)
SPI4_MOSI: U1.44 (PE14), U3.14 (AP_SDA/AP_SDIO/AP_SDI)
SPI4_SCK: U1.42 (PE12), U3.13 (AP_SCL/AP_SCLK)
SWCLK: J19.4, U1.76 (PA14)
SWDIO: J19.2, U1.72 (PA13)
TUNER_ADDR: R29.2, U13.28 (ADDR)
TUNER_REF: C58.1, Y2.3 (OUTPUT RF)
TUNER_XTAL: C58.2, U13.14 (XTAL)
UART7_CTS: J21.4, U1.40 (PE10), U28.4 (D2+), U28.7 (NC)
UART7_RTS: J21.5, U1.39 (PE9), U28.5 (D2-), U28.6 (NC)
UART7_RX: J21.3, U1.37 (PE7), U28.2 (D1-), U28.9 (NC)
UART7_TX: J21.2, U1.38 (PE8), U28.1 (D1+), U28.10 (NC)
USART1_RX: R73.2, U1.69 (PA10)
USART1_RX_J: J11.3, R73.1, U30.2 (D1-), U30.9 (NC)
USART1_TX: R72.2, U1.68 (PA9)
USART1_TX_J: J11.2, R72.1, U30.1 (D1+), U30.10 (NC)
USART2_RX: J3.3, U1.87 (PD6), U22.3 (IO2)
USART2_TX: J3.2, U1.86 (PD5), U22.1 (IO1)
USART6_TX: J5.2, U1.63 (PC6), U23.1 (IO1)
USB_DM: U1.70 (PA11), U12.4 (I/O2)
USB_DM_CON: J1.A7 (Dn1), J1.B7 (Dn2), U12.3 (I/O2)
USB_DP: U1.71 (PA12), U12.6 (I/O1)
USB_DP_CON: J1.A6 (Dp1), J1.B6 (Dp2), U12.1 (I/O1)
VBAT: C17.1, C18.1, C19.1, C66.1, DZ1.1 (K), PF1.1, Q4.2 (S), R4.1, R18.1, R40.1, U8.2 (VIN), U8.10 (VIN), U20.2 (VIN), U20.10 (VIN)
VBAT_GATE: DZ1.2 (A), Q4.1 (G), R46.1
VBAT_IN: D1.1 (C), J2.2, PF9.1, Q4.3 (D)
VBUS: C42.1, D_USB.2 (+), J1.A4B9 (VBUS), J1.B4A9 (VBUS), PF7.1, U12.5 (VBUS)
VCAP1: C8.1, U1.48 (VCAP)
VCAP2: C9.1, U1.73 (VCAP)
VCC_RF: C49.1, C50.1, C51.1, C84.1, C86.1, PF8.1, R28.2, R58.1, U13.1 (VCC_RF2), U13.2 (VCC_RF1), U13.6 (VCC_LO), U13.7 (VCC_VCO), U13.13 (VCC_SYN), U13.16 (VCC_DIG), U13.25 (VCC_BB)
VCOBYP: C60.1, U13.8 (VCOBYP)
VDDA: C10.1, C11.1, C12.1, C13.1, L1.2, PF6.1, U1.20 (VREF+), U1.21 (VDDA)
VTUNE: C56.1, R57.2, U13.9 (VTUNE)
WS2812: U1.67 (PA8), U17.2 (A)
WS2812_OUT: P152.1, U17.4 (Y)

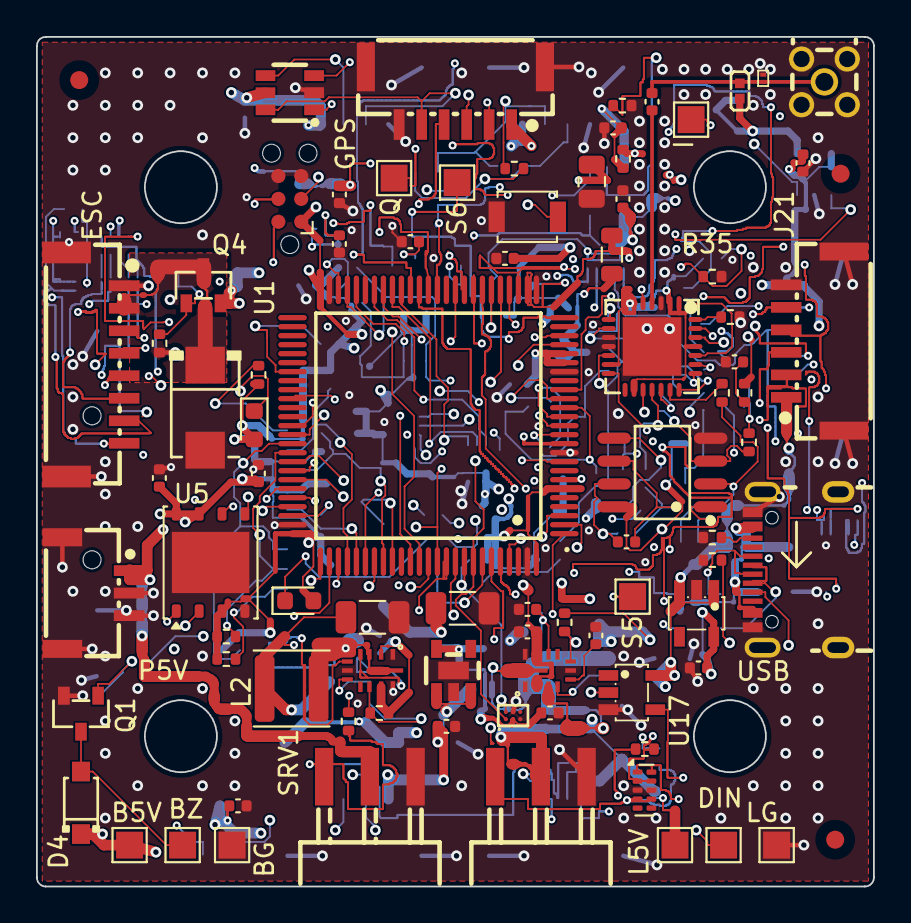
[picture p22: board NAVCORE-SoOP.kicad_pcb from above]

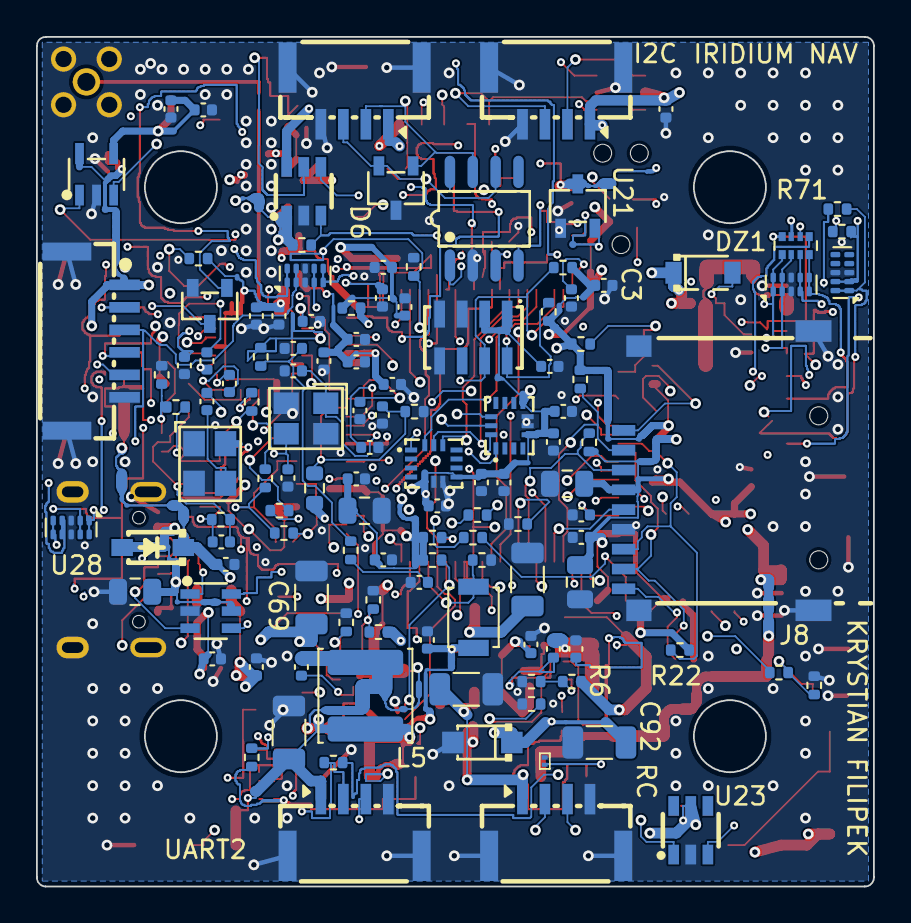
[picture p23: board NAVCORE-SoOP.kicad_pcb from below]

Board: 6 copper layers, 46.5 x 47.2 mm, 208 parts (123 on the bottom side), 137 nets.

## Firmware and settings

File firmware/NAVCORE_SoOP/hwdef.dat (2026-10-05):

# hwdef for NAVCORE-SoOP
# Generated by tools/gen_hwdef.py from the vendored MatekH743 reference plus the deltas below.
# hw definition file for processing by chibios_pins.py
# for NAVCORE-SoOP (45 x 47 mm, 30.5 mm stack)

# MCU class and specific type
MCU STM32H7xx STM32H743xx

# board ID. See Tools/AP_Bootloader/board_types.txt
APJ_BOARD_ID AP_HW_NAVCORE_SOOP    # 9001, unregistered

# crystal frequency, setup to use external oscillator
OSCILLATOR_HZ 8000000

FLASH_SIZE_KB 2048

# bootloader takes first sector
FLASH_RESERVE_START_KB 128


# ChibiOS system timer
STM32_ST_USE_TIMER 12
define CH_CFG_ST_RESOLUTION 16

# USB
PA11 OTG_FS_DM OTG1
PA12 OTG_FS_DP OTG1

PA13 JTMS-SWDIO SWD
PA14 JTCK-SWCLK SWD

# SPI1 for IMU1 (MPU6000)
PA5 SPI1_SCK SPI1
PA6 SPI1_MISO SPI1
PD7 SPI1_MOSI SPI1
PC15 IMU1_CS CS

# SPI2 for MAX7456 OSD
# [removed: no analogue OSD fitted] PB12 MAX7456_CS CS
# [removed: SPI2 served only the analogue OSD, which is not fitted] PB13 SPI2_SCK SPI2
# [removed: SPI2 served only the analogue OSD, which is not fitted] PB14 SPI2_MISO SPI2
# [removed: SPI2 served only the analogue OSD, which is not fitted] PB15 SPI2_MOSI SPI2

# SPI3 - external
PB3 SPI3_SCK SPI3
PB4 SPI3_MISO SPI3
PB5 SPI3_MOSI SPI3

# external CS pins
# [was: PD4 EXT_CS1 CS]
# The flow port's chip select leaves PD4, on U1's north-west corner, for PC13
# on the east side facing J14 and its clamp U29: the long run across the board
# would not route. PC13 is a low-drive RTC-domain pin (3 mA, 2 MHz), which a
# chip select that toggles once per transaction does not notice.
PC13 EXT_CS1 CS
PE2 EXT_CS2 CS

# SPI4 for IMU2 (ICM20602)
PE11 IMU2_CS CS
PE12 SPI4_SCK SPI4
PE13 SPI4_MISO SPI4
PE14 SPI4_MOSI SPI4

# add ICM42605 on SPI4 as a backup to replace ICM20602
# [removed: no third IMU fitted; PC13 is the flow port's chip select] PC13 IMU3_CS CS

# two I2C bus
I2C_ORDER I2C2 I2C1

# I2C1
PB6 I2C1_SCL I2C1
PB7 I2C1_SDA I2C1

# I2C2
PB10 I2C2_SCL I2C2
PB11 I2C2_SDA I2C2

# ADC
# [was: PC0 BATT_VOLTAGE_SENS ADC1 SCALE(1)]
# Battery sensing moves to ADC3 (PC0 is ADC123_INP10, the same channel
# number), so ADC1 and ADC2 are free to sample the tuner's I and Q together -
# AP_SoOP_Capture.
PC0 BATT_VOLTAGE_SENS ADC3 SCALE(1)
# [was: PC1 BATT_CURRENT_SENS ADC1 SCALE(1)]
# Battery current moves to ADC3 with the voltage (PC1 is ADC123_INP11).
PC1 BATT_CURRENT_SENS ADC3 SCALE(1)
# [removed: single battery; freed for the SoOP I/Q input] PA4 BATT2_VOLTAGE_SENS ADC1 SCALE(1)
# [was: PA7 BATT2_CURRENT_SENS ADC1 SCALE(1)]
# MatekH743 reads PA7 as BATT2_CURRENT_SENS. This board has one battery, so
# the pin was free, and it now drives Q3's gate to switch the 5 V Payload rail
# (U20). LOW leaves the rail enabled - R45 pulls the gate down as well - so
# payload fails safe towards powered. It is deliberately a pin MatekH743 only
# ever READS: a stock MatekH743 binary cannot assert it and so cannot cut
# payload power.
PA7 PAYLOAD_EN OUTPUT LOW GPIO(83)

define HAL_BATT_MONITOR_DEFAULT 4
define HAL_BATT_VOLT_PIN 10
define HAL_BATT_CURR_PIN 11
# [removed: single battery] define HAL_BATT2_VOLT_PIN 18
# [removed: single battery] define HAL_BATT2_CURR_PIN 7
define HAL_BATT_VOLT_SCALE 11.0
define HAL_BATT_CURR_SCALE 40.0
# [removed: single battery] define HAL_BATT2_VOLT_SCALE 11.0

# [was: PC4 PRESSURE_SENS ADC1 SCALE(2)]
# No airspeed sensor: PC4 is the tuner's I, through the OPA2374 stage.
# Declared on ADC1 so the DMA resolver gives ADC1/ADC2 a stream of their own;
# AnalogIn leaves ADC1 alone (tools/install_soop_backend.py) and
# AP_SoOP_Capture samples it with Q on ADC2.
PC4 SOOP_I_ADC ADC1 SCALE(1)
# [removed: no airspeed sensor] define HAL_DEFAULT_AIRSPEED_PIN 4

# [was: PC5 RSSI_ADC ADC1]
# RSSI arrives over CRSF, so PC5 enables U24, the antenna's bias feed. HIGH,
# and R59 pulls it up, so the feed is on from power-up; AP_SoOP switches it
# off on a lasting short or when soop.cfg says ant_feed 0.
PC5 BIAS_EN OUTPUT HIGH GPIO(84)
# [removed: RSSI arrives over CRSF] define BOARD_RSSI_ANA_PIN 8

# LED
# green LED1 marked as B/E
# blue LED0 marked as ACT
define AP_NOTIFY_GPIO_LED_2_ENABLED 1
PE3 LED0 OUTPUT LOW GPIO(90) # blue
PE4 LED1 OUTPUT LOW GPIO(91) # green
define HAL_GPIO_A_LED_PIN 91
define HAL_GPIO_B_LED_PIN 90

# order of UARTs (and USB)
# [was: SERIAL_ORDER OTG1 UART7 USART1 USART2 USART3 UART8 UART4 USART6 OTG2]
# UART4 gave PB8 to PWM7. EMPTY keeps every other SERIALn where MatekH743 has
# it.
SERIAL_ORDER OTG1 UART7 USART1 USART2 USART3 UART8 EMPTY USART6 OTG2

# USART1 (telem2)
PA10 USART1_RX USART1
PA9  USART1_TX USART1

# USART2 (GPS1)
PD5 USART2_TX USART2
PD6 USART2_RX USART2

# USART3 (GPS2)
PD9 USART3_RX USART3
PD8 USART3_TX USART3

# UART4 (spare)
# [removed: UART4 was never brought out; PB8 now carries servo PWM7] PB9 UART4_TX UART4
# [removed: UART4 was never brought out; PB8 now carries servo PWM7] PB8 UART4_RX UART4

# USART6 (RC input), SERIAL7
# [removed: RC is CRSF over USART6 (SERIAL7_PROTOCOL 23), so the timer input on the same pin goes, and TIM3 drives M1/M2 instead (PPM/SBUS-by-timer receivers lose their input)] PC7 TIM3_CH2 TIM3 RCININT PULLDOWN LOW
PC6 USART6_TX USART6 NODMA

# as an alternative config setup the RX6 pin as a uart. This allows
# for bi-directional UART based receiver protocols such as FPort
# without any extra hardware
# [was: PC7 USART6_RX USART6 NODMA ALT(1)]
# USART6_RX is PC7's only function now that the timer RC input is gone.
PC7 USART6_RX USART6 NODMA

# UART7 (telem1)
PE7 UART7_RX UART7
PE8 UART7_TX UART7
PE10 UART7_CTS UART7
PE9  UART7_RTS UART7

# UART8 (spare)
PE0 UART8_RX UART8
# [removed: ESC telemetry is receive-only, so UART8 needs only PE0/RX. PE1 is left unwired rather than declared and unconnected] PE1 UART8_TX UART8

# CAN bus
PD0 CAN1_RX CAN1
PD1 CAN1_TX CAN1
PD3 GPIO_CAN1_SILENT OUTPUT PUSHPULL SPEED_LOW LOW GPIO(70)

# Motors
# [was: PB0  TIM8_CH2N TIM8  PWM(1)  GPIO(50)]
# M1 moves from TIM8_CH2N (complementary - no input capture, so no BDShot) to
# TIM3_CH3 on the same pin, as MatekH743-bdshot does. BIDIR is set on the
# first channel of each pair, which reads for both.
PB0  TIM3_CH3 TIM3  PWM(1)  GPIO(50) BIDIR
# [was: PB1  TIM8_CH3N TIM8  PWM(2)  GPIO(51)]
# M2: TIM3_CH4, same pin.
PB1  TIM3_CH4 TIM3  PWM(2)  GPIO(51)
# [was: PA0  TIM5_CH1  TIM5  PWM(3)  GPIO(52)]
# M3/M4 stay on TIM5 (MatekH743-bdshot moves them to TIM2, but TIM2_CH1 is the
# passive buzzer's tone on PA15).
PA0  TIM5_CH1  TIM5  PWM(3)  GPIO(52) BIDIR
PA1  TIM5_CH2  TIM5  PWM(4)  GPIO(53)
# [was: PA2  TIM5_CH3  TIM5  PWM(5)  GPIO(54)]
# The spare servo output on test pad TP3 moves from PA2, whose escape faces
# the RF corner, to PB9 on U1's south edge beside TP3. It joins the servos'
# TIM4 rate group, and leaves TIM5 to the motors.
PB9 TIM4_CH4 TIM4 PWM(5) GPIO(54)
PA3  TIM5_CH4  TIM5  PWM(6)  GPIO(55)
# [was: PD12 TIM4_CH1 TIM4 PWM(7) GPIO(56)]
# Servo 1 (J17) moves from PD12 on U1's west side to PB8 on the south edge,
# nearer J17: the run round U1 would not route. Same timer (TIM4) as PWM8, so
# the two servos keep one rate group.
PB8 TIM4_CH3 TIM4 PWM(7) GPIO(56)
PD13 TIM4_CH2 TIM4 PWM(8) GPIO(57)
# [removed: PWM9 had no connector; TIM4_CH3 is PWM7's on PB8] PD14 TIM4_CH3 TIM4 PWM(9) GPIO(58)
# [removed: PWM10 had no connector; TIM4_CH4 is PWM5's on PB9] PD15 TIM4_CH4 TIM4 PWM(10) GPIO(59)
PE5  TIM15_CH1 TIM15 PWM(11) GPIO(60)
PE6  TIM15_CH2 TIM15 PWM(12) GPIO(61)
PA8 TIM1_CH1 TIM1 PWM(13) GPIO(62) # for WS2812 LED

# Beeper
PA15 TIM2_CH1 TIM2 GPIO(32) ALARM

# microSD support
PC8 SDMMC1_D0 SDMMC1
PC9 SDMMC1_D1 SDMMC1
PC10 SDMMC1_D2 SDMMC1
PC11 SDMMC1_D3 SDMMC1
PC12 SDMMC1_CK SDMMC1
PD2 SDMMC1_CMD SDMMC1

# GPIOs
# [was: PD10  PINIO1 OUTPUT GPIO(81) LOW]
# U24's FAULT#, open drain, pulled up by R60: low on overcurrent,
# overtemperature or reverse voltage.
PD10 BIAS_FAULT INPUT GPIO(85)
# [was: PD11  PINIO2 OUTPUT GPIO(82) LOW]
# PD11 is reserved for an optical flow motion interrupt. It is not wired on
# Rev C (J14.6 is GND), so the pull-down holds it idle.
PD11 FLOW_MOTION INPUT PULLDOWN GPIO(86)

DMA_PRIORITY S*

define HAL_STORAGE_SIZE 32768

# use last 2 pages for flash storage
# H743 has 16 pages of 128k each
STORAGE_FLASH_PAGE 14

# spi devices
SPIDEV icm42688  SPI1 DEVID1 IMU1_CS      MODE3  2*MHZ 16*MHZ   # Clock is 100Mhz so highest clock <= 24Mhz is 100Mhz/8
# [removed: MPU6000 not fitted] SPIDEV mpu6000   SPI1 DEVID1 IMU1_CS      MODE3  1*MHZ  4*MHZ
# [removed: ICM-20602 not fitted] SPIDEV icm20602  SPI4 DEVID1 IMU2_CS      MODE3  1*MHZ  4*MHZ
# [was: SPIDEV icm42605  SPI4 DEVID1 IMU3_CS      MODE3  2*MHZ 16*MHZ]
# U3's CS pad is wired to PE11 (IMU2_CS), read from the board.
SPIDEV icm42605  SPI4 DEVID1 IMU2_CS      MODE3  2*MHZ 16*MHZ
# [removed: no analogue OSD fitted] SPIDEV osd       SPI2 DEVID4 MAX7456_CS   MODE0 10*MHZ 10*MHZ


# [was: DMA_NOSHARE SPI1* SPI4*]
# the BDShot timers get DMA streams of their own, as the IMU buses do
DMA_NOSHARE SPI1* SPI4* TIM3* TIM5*
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

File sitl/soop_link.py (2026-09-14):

#!/usr/bin/env python3
#feed ArduCopter SITL a fix as bad as an Iridium Doppler solve, and measure the EKF
#Usage:
#soop_link.py --mode extnav --duration 120 --report /tmp/nav/sitl/extnav.json
import argparse, json, math, os, random, sys, time
from collections import deque

try:
    from pymavlink import mavutil
except ImportError:
    sys.exit("pymavlink missing - pip install pymavlink into the venv")

EARTH_R = 6378137.0


#Small-angle equirectangular projection about the origin
def latlon_to_ned(lat, lon, alt, olat, olon, oalt):
    dlat = math.radians(lat - olat)
    dlon = math.radians(lon - olon)
    n = dlat * EARTH_R
    e = dlon * EARTH_R * math.cos(math.radians(olat))
    d = -(alt - oalt)
    return n, e, d


def ned_to_latlon(n, e, olat, olon):
    lat = olat + math.degrees(n / EARTH_R)
    lon = olon + math.degrees(e / (EARTH_R * math.cos(math.radians(olat))))
    return lat, lon


#Latency, a slow random-walk bias, white noise and outages
class DopplerErrorModel:

    SIGMA_IRIDIUM_NO_ELEV = 180.0    #mean eastward error, Iridium NEXT, no elev aiding
    SIGMA_IRIDIUM_MAE = 380.0        #mean absolute error, same conditions
    SIGMA_SINGLE_SAT = 656.0         #Doppler-only, one satellite
    SIGMA_SINGLE_SAT_DOA = 289.5     #one satellite, + azimuth doa
    SIGMA_BEST_MULTI = 22.7          #4 Iridium + 1 Orbcomm, static - best case, not typical

    def __init__(self, sigma_m=SIGMA_IRIDIUM_NO_ELEV, bias_walk_m_s=1.5, bias_cap_m=40.0,
                 latency_s=2.0, rate_hz=1.0, outage_p=0.05, outage_len_s=8.0,
                 seed=None):
        self.sigma = sigma_m
        self.walk = bias_walk_m_s
        self.cap = bias_cap_m
        self.latency = latency_s
        self.period = 1.0 / rate_hz
        self.outage_p = outage_p
        self.outage_len = outage_len_s
        self.rng = random.Random(seed)
        self.bias = [0.0, 0.0]
        self.buf = deque()            #(ready_at, n, e, d) - the latency line
        self.next_emit = 0.0
        self.outage_until = 0.0
        self.resets = 0
        self._last_bias_t = None

    #random walk, reflected at the cap so the bias wanders but stays bounded
    def _advance_bias(self, now):
        dt = 0.0 if self._last_bias_t is None else now - self._last_bias_t
        self._last_bias_t = now
        for i in (0, 1):
            self.bias[i] += self.rng.gauss(0.0, self.walk * math.sqrt(max(dt, 0.0)))
            if abs(self.bias[i]) > self.cap:
                self.bias[i] = math.copysign(self.cap, self.bias[i])

    #feed truth in; it comes out later, or not at all
    def offer(self, now, n, e, d):
        if now >= self.next_emit:
            self.next_emit = now + self.period
            if now < self.outage_until:
                return
            if self.rng.random() < self.outage_p:
                self.outage_until = now + self.outage_len
                #an outage means the next fix is a discontinuity; the EKF must be told
                self.resets += 1
                return
            self._advance_bias(now)
            self.buf.append((now + self.latency,
                             n + self.bias[0] + self.rng.gauss(0, self.sigma),
                             e + self.bias[1] + self.rng.gauss(0, self.sigma),
                             d + self.rng.gauss(0, self.sigma * 0.5)))

    def due(self, now):
        while self.buf and self.buf[0][0] <= now:
            yield self.buf.popleft()


class Harness:
    VEL_SIGMA = 0.3
    FLOW_SIGMA = 0.02          #rad/s; a decent camera flow solution
    PRX_MAX_CM = 400           #sensor ceiling reported to ArduPilot, cm
    PRX_CLEAR_CM = 350

    def rng_v(self):
        return self.model.rng.gauss(0.0, self.VEL_SIGMA)

    def __init__(self, conn, mode, model, flow_hz=20.0, flow_quality=180, bias_m=0.0,
                 honest_quality=False, mirror_gps=True):
        self.vel_sigma = self.VEL_SIGMA
        #mirror the live GPS onto instance 2 while GPS1 is healthy
        self.mirror_gps = mirror_gps
        self._gps1_rx_t = None
        self.honest_quality = honest_quality
        self.bias_m = bias_m
        self.bias_active = False
        self.m = conn
        self.mode = mode
        self.model = model
        self.flow_dt = 1.0 / flow_hz
        self.flow_quality = flow_quality
        self.origin = None            #(lat, lon, alt) of the EKF origin
        self.truth = None             #(lat, lon, alt) from SIMSTATE
        self.est = None               #(lat, lon, alt) from GLOBAL_POSITION_INT
        self.vel = (0.0, 0.0, 0.0)    #NED m/s
        self.agl = 0.0                #height above the launch point, m
        self._last_truth_t = None
        self.send_velocity = True     #cleared by the position-only comparison scenario
        self.yaw = 0.0                #rad
        self.next_flow = 0.0
        self.next_obst = 0.0
        self.errors = []              #(t, horizontal error m)
        self.truth_track = []
        self.track = []               #(t, truth_n, truth_e, est_n, est_e) for inspection
        self.alt_track = []           #height above launch, for the flow-ceiling test
        self.alt_track_denied = None  #set to [] at denial; only these count for a ceiling
        self.t0 = time.time()

    #inbound
    #read everything pending. the only reader - see the note in scenarios.py
    def pump(self):
        n = 0
        while True:
            msg = self.m.recv_match(blocking=False)
            if msg is None:
                return n
            if msg.get_type() != "BAD_DATA":
                n += 1
            t = msg.get_type()
            if t == "SIMSTATE":
                new = (msg.lat * 1e-7, msg.lng * 1e-7, getattr(msg, "alt", 0.0))
                self._truth_velocity(new)
                self.truth = new
            elif t == "GPS_GLOBAL_ORIGIN":
                self.origin = (msg.latitude * 1e-7, msg.longitude * 1e-7,
                               msg.altitude * 1e-3)
            elif t == "GLOBAL_POSITION_INT":
                self.est = (msg.lat * 1e-7, msg.lon * 1e-7, msg.alt * 1e-3)
                self.agl = max(msg.relative_alt / 1000.0, 0.0)
                self.alt_track.append(self.agl)
                if self.alt_track_denied is not None:
                    self.alt_track_denied.append(self.agl)
                #note: msg.vx/vy/vz are the EKF's own velocity estimate
            elif t == "GPS_RAW_INT":
                if getattr(msg, "fix_type", 0) >= 3:
                    self._gps1_rx_t = time.time()
            elif t == "ATTITUDE":
                self.yaw = msg.yaw

    #differentiate SIMSTATE to get true velocity
    def _truth_velocity(self, new):
        now = time.time()
        if self.truth is not None and self._last_truth_t is not None:
            dt = now - self._last_truth_t
            if dt > 0.02:
                dn, de, dd = latlon_to_ned(*new, *self.truth)
                self.vel = (dn / dt, de / dt, dd / dt)
                self._last_truth_t = now
        else:
            self._last_truth_t = now

    #outbound
    def send_position(self, now):
        if self.truth is None:
            return
        if self.origin is None:
            #no origin yet - ask for it
            self.m.mav.command_long_send(
                self.m.target_system, self.m.target_component,
                mavutil.mavlink.MAV_CMD_REQUEST_MESSAGE, 0,
                mavutil.mavlink.MAVLINK_MSG_ID_GPS_GLOBAL_ORIGIN, 0, 0, 0, 0, 0, 0)
            return
        n, e, d = latlon_to_ned(*self.truth, *self.origin)
        self.model.offer(now, n, e, d)
        gps1_alive = (self._gps1_rx_t is not None
                      and (time.time() - self._gps1_rx_t) < 2.0)
        for _ready, dn, de, dd in self.model.due(now):
            #the offset is applied only once armed
            dn += self.bias_m if self.bias_active else 0.0
            usec = int(now * 1e6)
            if self.mode == "extnav":
                self.m.mav.vision_position_estimate_send(
                    usec, dn, de, dd, 0.0, 0.0, 0.0,
                    reset_counter=self.model.resets)
            else:
                #mirror decision per published fix
                mirror = (self.mirror_gps and not self.bias_active and gps1_alive)
                if mirror:
                    mlat, mlon = self.truth[0], self.truth[1]
                    malt = self.truth[2]
                    msacc, mhacc, mnsats = 0.3, 2.0, 12
                else:
                    mlat, mlon = ned_to_latlon(dn, de, self.origin[0], self.origin[1])
                    malt = self.origin[2] - dd
                    msacc, mhacc, mnsats = self._quality(now)
                lat, lon = mlat, mlon
                #keywords, not positional
                vn = self.vel[0] + self.rng_v()
                ve = self.vel[1] + self.rng_v()
                vd = self.vel[2] + self.rng_v()
                self.m.mav.gps_input_send(
                    time_usec=usec,
                    #ZERO-BASED instance index
                    gps_id=1,
                    #8|16|32 = ignore vel_horiz, vel_vert, speed_accuracy
                    ignore_flags=0 if self.send_velocity else (8 | 16 | 32),
                    time_week_ms=0,
                    time_week=0,
                    fix_type=3,                       #3D
                    lat=int(lat * 1e7),
                    lon=int(lon * 1e7),
                    alt=malt,
                    hdop=1.0,
                    vdop=1.0,
                    vn=vn, ve=ve, vd=vd,
                    speed_accuracy=msacc,
                    horiz_accuracy=mhacc,             #the EKF weights on these
                    vert_accuracy=mhacc * 0.5,
                    satellites_visible=mnsats)

    #the quality fields the companion publishes
    def _quality(self, now):
        if not self.honest_quality:
            return self.vel_sigma, self.model.sigma, 8
        stale = now < self.model.outage_until + 2.0
        if stale:
            return 3.0, self.model.sigma * 3.0, 4
        return self.vel_sigma, self.model.sigma, 8

    #emit flow derived from the vehicle's actual motion
    def send_flow(self, now):
        if now < self.next_flow:
            return
        self.next_flow = now + self.flow_dt

        vn, ve, _vd = self.vel
        c, s_ = math.cos(self.yaw), math.sin(self.yaw)
        vx_body = vn * c + ve * s_          #forward
        vy_body = -vn * s_ + ve * c         #right

        if self.agl < 1.0:
            rate_x = rate_y = 0.0
            quality = 0
        else:
            rate_x = vy_body / self.agl
            rate_y = -vx_body / self.agl
            n = self.model.rng.gauss
            rate_x += n(0.0, self.FLOW_SIGMA)
            rate_y += n(0.0, self.FLOW_SIGMA)
            quality = self.flow_quality

        self.m.mav.optical_flow_send(
            int(now * 1e6), 0,
            0, 0,                                 #flow_x/y unused; rates below win
            0.0, 0.0,
            quality,
            self.agl,                             #AP ignores it; sent for completeness
            flow_rate_x=rate_x, flow_rate_y=rate_y)

    #emit OBSTACLE_DISTANCE as the 8-sensor ToF ring would
    def send_obstacles(self, now, wall_at_m=None):
        if now < self.next_obst:
            return
        self.next_obst = now + 0.1                     #10 Hz
        self.obst_sent = getattr(self, "obst_sent", 0) + 1
        NOT_SEEN = 65535                               #"unknown", per the message spec
        d = [NOT_SEEN] * 72
        for i in range(8):
            if wall_at_m is not None and i == 0:       #sector 0 = straight ahead
                d[i] = int(wall_at_m * 100)            #centimetres
            else:
                d[i] = int(self.PRX_CLEAR_CM)          #clear, and inside the max
        self.m.mav.obstacle_distance_send(
            time_usec=int(now * 1e6),
            sensor_type=0,                             #MAV_DISTANCE_SENSOR_LASER
            distances=d,
            increment=45,                              #8 sectors x 45 deg
            min_distance=20,                           #cm
            max_distance=int(self.PRX_MAX_CM),
            increment_f=0.0,                           #0 = use the integer increment
            angle_offset=0.0,                          #sector 0 starts dead ahead
            frame=12)                                  #MAV_FRAME_BODY_FRD

    #measurement
    def sample_error(self, now):
        if self.truth is None or self.est is None or self.origin is None:
            return
        tn, te, _ = latlon_to_ned(*self.truth, *self.origin)
        en, ee, _ = latlon_to_ned(*self.est, *self.origin)
        self.errors.append((now - self.t0, math.hypot(tn - en, te - ee)))
        self.truth_track.append((tn, te))
        self.track.append((round(now - self.t0, 1), round(tn, 1), round(te, 1),
                           round(en, 1), round(ee, 1)))

    def summary(self):
        if not self.errors:
            return {"samples": 0, "error": "no paired truth/estimate samples"}
        e = [v for _t, v in self.errors]
        e_sorted = sorted(e)
        return {
            "mode": self.mode,
            "samples": len(e),
            "mean_err_m": round(sum(e) / len(e), 2),
            "p50_err_m": round(e_sorted[len(e) // 2], 2),
            "p95_err_m": round(e_sorted[int(len(e) * 0.95)], 2),
            "max_err_m": round(max(e), 2),
            "injected_sigma_m": self.model.sigma,
            "injected_latency_s": self.model.latency,
            "injected_rate_hz": round(1.0 / self.model.period, 2),
            "outages": self.model.resets,
        }


def main():
    ap = argparse.ArgumentParser()
    ap.add_argument("--connect", default="tcp:127.0.0.1:5760")
    ap.add_argument("--mode", choices=["extnav", "gpsinput"], default="extnav")
    ap.add_argument("--duration", type=float, default=120.0)
    #the class default is 180 (SIGMA_IRIDIUM_NO_ELEV, the published Iridium NEXT figure)
    ap.add_argument("--sigma", type=float, default=DopplerErrorModel.SIGMA_IRIDIUM_NO_ELEV)
    ap.add_argument("--latency", type=float, default=2.0)
    ap.add_argument("--rate", type=float, default=1.0)
    ap.add_argument("--outage-p", type=float, default=0.05)
    ap.add_argument("--seed", type=int, default=1)
    ap.add_argument("--report", default=None)
    a = ap.parse_args()

    conn = mavutil.mavlink_connection(a.connect, source_system=1, source_component=191)
    print(f"waiting for heartbeat on {a.connect} ...", flush=True)
    conn.wait_heartbeat(timeout=60)
    print(f"connected: system {conn.target_system}", flush=True)

    conn.mav.request_data_stream_send(conn.target_system, conn.target_component,
                                      mavutil.mavlink.MAV_DATA_STREAM_ALL, 20, 1)

    h = Harness(conn, a.mode,
                DopplerErrorModel(sigma_m=a.sigma, latency_s=a.latency,
                                  rate_hz=a.rate, outage_p=a.outage_p, seed=a.seed))
    end = time.time() + a.duration
    next_sample = 0.0
    while time.time() < end:
        now = time.time()
        h.pump()
        h.send_position(now)
        h.send_flow(now)
        if now >= next_sample:
            next_sample = now + 0.2
            h.sample_error(now)
        time.sleep(0.005)

    s = h.summary()
    print(json.dumps(s, indent=2))
    if a.report:
        os.makedirs(os.path.dirname(a.report), exist_ok=True)
        with open(a.report, "w") as f:
            json.dump(s, f, indent=2)
    return 0


if __name__ == "__main__":
    sys.exit(main())

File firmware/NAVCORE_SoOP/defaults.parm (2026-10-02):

# Default parameters for NAVCORE-SoOP.
# Generated by tools/gen_hwdef.py - do not hand-edit.

# --- airframe -------------------------------------------------------------
FRAME_CLASS 1
FRAME_TYPE 1

# --- motors: DShot600 into the SpeedyBee 4-in-1 ---------------------------
MOT_PWM_TYPE 6

# --- serial ---------------------------------------------------------------
SERIAL1_PROTOCOL 2
SERIAL1_BAUD 921
SERIAL3_PROTOCOL 5
SERIAL5_PROTOCOL 16
SERIAL5_BAUD 115
SERIAL7_PROTOCOL 23

BATT_MONITOR 4
# BATT_VOLT_MULT is the fitted divider: 10k / 1k.
BATT_VOLT_MULT 11.000
BATT_AMP_PERVLT 25.0

RNGFND1_TYPE 0
RNGFND1_ORIENT 25
RNGFND1_MIN 0.20
RNGFND1_MAX 15.00


RNGFND3_TYPE 0
RNGFND3_ADDR 41
RNGFND3_ORIENT 24
RNGFND3_MIN 0.04
RNGFND3_MAX 3.60

# Keep FLOW_TYPE 5 while any EK3_SRCn_VELXY is 5 (optical flow), or the EKF refuses to arm.
FLOW_TYPE 5
# Whatever produces the flow, its X/Y axes are not necessarily the vehicle's.
FLOW_ORIENT_YAW 0

RC_PROTOCOLS 512

# No separate telemetry radio is fitted or needed.

SERVO_BLH_AUTO 1
# 2806.5 motors are 12N14P.
SERVO_BLH_POLES 14

# Throttle-referenced notch until there is RPM telemetry. ~108 Hz is the expected hover
# (docs/VERIFICATION.md); set FREQ/REF from the first hover's FFT log (runbook T5).
INS_HNTCH_ENABLE 1
INS_HNTCH_MODE 1
INS_HNTCH_REF 0.35
INS_HNTCH_FREQ 80
INS_HNTCH_BW 40
INS_HNTCH_HMNCS 3
# Bidirectional DShot: the hwdef supports it on motors 1-4 (BIDIR on TIM3/TIM5), but the
# BLS 60A ships BLHeli_S, which never answers. After flashing Bluejay (runbook T3) set
# SERVO_BLH_BDMASK 15 and INS_HNTCH_MODE 3. Shipped off, so a stock ESC still spins.
SERVO_BLH_BDMASK 0

GPS2_TYPE 0
GPS_AUTO_SWITCH 1
VISO_TYPE 0

EK3_SRC1_POSXY 3
EK3_SRC1_VELXY 3
EK3_SRC1_POSZ 1
EK3_SRC1_VELZ 3
EK3_SRC1_YAW 1
EK3_SRC2_POSXY 0
EK3_SRC2_VELXY 5
EK3_SRC2_POSZ 1
EK3_SRC2_VELZ 0
EK3_SRC2_YAW 1
EK3_SRC3_POSXY 0
EK3_SRC3_VELXY 5
EK3_SRC3_POSZ 1
EK3_SRC3_VELZ 0
EK3_SRC3_YAW 1

RELAY1_FUNCTION 1
RELAY1_PIN 83
RELAY1_DEFAULT 0

FS_EKF_THRESH 1.0
# FS_EKF_ACTION 0 relies on the dead-reckoning script (DR_ENABLE 1). If the script is not
# on the SD card, set it back to 1 - these change together with FS_THR_ENABLE and DR_ENABLE.
FS_EKF_ACTION 0

# Radio failsafe -> RTL.
FS_THR_ENABLE 1

# GCS failsafe OFF.
FS_GCS_ENABLE 0


SCR_ENABLE 1
# SCR_HEAP_SIZE 80000: the applet's own documented minimum. The default 41 KB is not
# enough and the script aborts at load with an out-of-memory error.
SCR_HEAP_SIZE 80000
# DR_ENABLE 1: arm the applet.
# The DR_* values document the dead-reckoning script's settings. The script creates these
# parameters after boot, so this file cannot set them; set them from the GCS.
DR_ENABLE 1
DR_ENABLE_DIST 30
DR_GPS_SACC_MAX 0.8
DR_GPS_SAT_MIN 6
DR_GPS_TRIGG_SEC 3
# DR_FLY_ANGLE 10 (applet default): conservative lean; most frames make max speed
# near 22 deg. Raise only after bench/hardware evidence.
DR_FLY_ANGLE 10
# DR_FLY_ALT_MIN 0: return at current altitude.
DR_FLY_ALT_MIN 0
DR_FLY_TIMEOUT 30
# DR_NEXT_MODE 6 (RTL): GO home and stay THERE.
DR_NEXT_MODE 6

# --- notify ---------------------------------------------------------------
# No safety switch is fitted, so arming must not wait for one.
BRD_SAFETY_DEFLT 0
NTF_LED_TYPES 257
SERVO13_FUNCTION 120

TEMP_LOG 1
TEMP1_TYPE 10
# Bus 1 is I2C1.
TEMP1_BUS 1
# 72 = 0x48, the TMP119 address with ADD0 tied to GND, which U19.C1 is. Parameter files
# are decimal: 0x48 written here parses as 0.
TEMP1_ADDR 72
# Source None - this is not an ESC, motor or battery temperature. It also keeps the
# reading logged under either TEMP_LOG setting.
TEMP1_SRC 0

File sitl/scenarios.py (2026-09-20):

#!/usr/bin/env python3
#fly ArduCopter SITL through the GNSS-denied sequence and measure what the EKF does
import argparse, json, math, os, subprocess, sys, time

sys.path.insert(0, os.path.dirname(os.path.abspath(__file__)))
from soop_link import Harness, DopplerErrorModel, latlon_to_ned

from pymavlink import mavutil

SRC_CHAN = 9           #RC9 carries RC9_OPTION 90, "EKF Source Set"
SRC_PWM = {1: 1000, 2: 1500, 3: 2000}

BOUNDARY_SIGMA_M = 20.0

BOUNDARY_SIGMA_SHIPPED_M = 180.0

SCENARIOS = {
    "baseline_gps": dict(
        mode=None, deny_at=None, src=1,
        why="GPS throughout. The floor - anything worse than this is the chain's fault.",
        max_p95=3.0),
    "soop_gpsinput": dict(
        mode="gpsinput", deny_at=40, src=1, startup={"GPS2_TYPE": 14}, rate=5.0,
        why="The shipped configuration. GPS denied; SoOP arrives as GPS_INPUT on instance 2 at 5 Hz - the companion interpolates up from the ~1 Hz Doppler solution",
        max_p95=None, informational=True, diverges_above=120.0),
    "soop_raw_1hz": dict(
        mode="gpsinput", deny_at=40, src=1, startup={"GPS2_TYPE": 14}, rate=1.0,
        why="Negative result. Publishing at the raw ~1 Hz solution rate must fail to arm",
        max_p95=None, expect_arm_failure="GPS 2"),
    "soop_no_velocity": dict(
        mode="gpsinput", deny_at=40, src=1, startup={"GPS2_TYPE": 14}, rate=5.0,
        no_velocity=True,
        why="What sending velocity is worth",
        max_p95=None, informational=True, diverges_above=120.0),
    "soop_dropout": dict(
        mode="gpsinput", deny_at=40, src=1, outage_p=0.25, startup={"GPS2_TYPE": 14},
        rate=5.0,
        why="SoOP itself drops out repeatedly during denial",
        max_p95=None, informational=True, diverges_above=120.0),
    #does the camera earn its weight?
    "soop_dropout_flow": dict(
        mode="gpsinput", deny_at=40, src=2, outage_p=0.25, rate=5.0,
        startup={"GPS2_TYPE": 14, "EK3_SRC2_POSXY": 3, "EK3_SRC2_VELXY": 5},
        why="The camera's value, measured - and it is zero here. soop_dropout with the EKF taking position from the SoOP fix and velocity from optical flow",
        max_p95=None, informational=True, diverges_above=120.0),

    #negative result, and it guards the indoor build
    "proximity_absent": dict(
        mode=None, deny_at=None, src=1, startup={"PRX1_TYPE": 2},
        why="Negative result, measured. PRX1_TYPE 2 with no proximity ring fitted refuses to ARM: 'Arm: PRX1: No Data'",
        max_p95=None, expect_arm_failure="PRX1"),

    #if it does
    "soop_dropout_honest": dict(
        mode="gpsinput", deny_at=40, src=1, outage_p=0.25, rate=5.0,
        startup={"GPS2_TYPE": 14}, honest_quality=True,
        why="The companion tells the truth. soop_dropout with degraded quality fields published while the SoOP solution is stale",
        max_p95=None, informational=True, diverges_above=120.0),

    #IF not the camera, then what?
    "soop_dropout_lowlat": dict(
        mode="gpsinput", deny_at=40, src=1, outage_p=0.25, rate=5.0, latency=0.5,
        startup={"GPS2_TYPE": 14},
        why="Latency sensitivity. soop_dropout with the SoOP fix arriving 0.5 s late instead of 2.0 s, everything else identical",
        max_p95=None, informational=True, diverges_above=120.0),
    "soop_dropout_lowsigma": dict(
        mode="gpsinput", deny_at=40, src=1, outage_p=0.25, rate=5.0, sigma=10.0,
        startup={"GPS2_TYPE": 14},
        why="Accuracy sensitivity. soop_dropout with a 10 m SoOP solution instead of the 180 m shipping sigma, everything else identical",
        max_p95=None, informational=True, diverges_above=120.0),
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

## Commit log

2026-08-25 initial NAVCORE-SoOP board and design scripts
    [BOM-NAVCORE-SoOP-economic.csv, BOM-NAVCORE-SoOP-nofpv.csv, BOM-NAVCORE-SoOP.csv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]
2026-09-03 add the order bundle and 3D renders
    [NAVCORE-SoOP-B_Cu.gbr, NAVCORE-SoOP-B_Mask.gbr, NAVCORE-SoOP-B_Paste.gbr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]
2026-09-07 move the SoOP tuner onto the board, add input protection and connector checks
    [defaults.parm]
2026-09-14 rev B re-layout and re-route
    [BOM-NAVCORE-SoOP-economic.csv, BOM-NAVCORE-SoOP-nofpv.csv, BOM-NAVCORE-SoOP.csv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]
2026-09-15 add U9 thermal vias and the Doppler solver, fix the order files
    [NAVCORE-SoOP-B_Cu.gbr, NAVCORE-SoOP-B_Mask.gbr, NAVCORE-SoOP-B_Paste.gbr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]
2026-09-16 re-route with freerouting and add the U19 temperature sensor
    [BOM-NAVCORE-SoOP.csv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]
2026-09-19 board ID 7180, the frame from its DXF and the firmware readme
    [BOM-NAVCORE-SoOP-economic.csv, BOM-NAVCORE-SoOP-nofpv.csv, BOM-NAVCORE-SoOP.csv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]
2026-09-20 SoOP solver end to end and SITL scenarios
    [BOM-NAVCORE-SoOP-economic.csv, BOM-NAVCORE-SoOP-nofpv.csv, BOM-NAVCORE-SoOP.csv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]
2026-09-21 rev C: payload buck, CAN, pyro and touchdown; re-place and re-route
    [BOM-NAVCORE-SoOP-economic.csv, BOM-NAVCORE-SoOP-nofpv.csv, BOM-NAVCORE-SoOP.csv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]
2026-09-22 rev C: rate the input for 5S and budget the payload rail
    [BOM-NAVCORE-SoOP-economic.csv, BOM-NAVCORE-SoOP-nofpv.csv, BOM-NAVCORE-SoOP.csv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]
2026-09-23 finish Rev C routing; SoOP EKF hand-off in SITL and SGP4 in C
    [NAVCORE-SoOP-B_Cu.gbr, NAVCORE-SoOP-B_Mask.gbr, NAVCORE-SoOP-B_Paste.gbr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]
2026-09-23 fix the In1 ground plane and the missing 3D models
    [NAVCORE-SoOP-B_Cu.gbr, NAVCORE-SoOP-B_Mask.gbr, NAVCORE-SoOP-B_Paste.gbr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]
2026-09-23 clean up copper and silkscreen, align the CPL to JLC footprints, clear J14 off the USB-C
    [CPL-NAVCORE-SoOP-economic.csv, CPL-NAVCORE-SoOP-nofpv.csv, CPL-NAVCORE-SoOP.csv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]
2026-09-23 add a backside check, move board-editing scripts out
    [NAVCORE-SoOP-B_Cu.gbr, NAVCORE-SoOP-B_Mask.gbr, NAVCORE-SoOP-B_Paste.gbr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]
2026-09-25 fix the tuner loop filter and IMU chip select, mark the forward edge
    [NAVCORE-SoOP.kicad_pcb, NAVCORE-SoOP.kicad_sch]
2026-09-25 bring the docs and order notes in line with the board
    [BOM-NAVCORE-SoOP-economic.csv, BOM-NAVCORE-SoOP-nofpv.csv, BOM-NAVCORE-SoOP.csv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]
2026-09-25 give the payload and analogue rails real copper, put C41 on the CAN supply
    [NAVCORE-SoOP-B_Cu.gbr, NAVCORE-SoOP-B_Mask.gbr, NAVCORE-SoOP-B_Paste.gbr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]
2026-09-26 fit 47 nF on the MAX2112 offset caps, as the datasheet asks
    [BOM-NAVCORE-SoOP-economic.csv, BOM-NAVCORE-SoOP-nofpv.csv, BOM-NAVCORE-SoOP.csv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]
2026-09-26 stop the artwork carrying part numbers that nothing checks
    [NAVCORE-SoOP-B_Cu.gbr, NAVCORE-SoOP-B_Mask.gbr, NAVCORE-SoOP-B_Paste.gbr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]
2026-09-26 simulate the three linear rails as well
2026-09-26 widen C29 to 2u2 and sync the LCSC properties
    [BOM-NAVCORE-SoOP-economic.csv, BOM-NAVCORE-SoOP-nofpv.csv, BOM-NAVCORE-SoOP.csv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]
2026-09-26 hold the pyro gate down with 10 nF, load-test the bucks on the bench
    [BOM-NAVCORE-SoOP-economic.csv, BOM-NAVCORE-SoOP-nofpv.csv, BOM-NAVCORE-SoOP.csv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]
2026-09-28 navigate from Iridium bursts on board, checked against a simulated sky
2026-09-29 printed mounts on heat-set inserts, nylon at the stack holes
    [antenna_tower.stl, drone.scad, frame.scad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]
2026-09-29 cross-check the GPS against an Iridium-only fix
    [AP_SoOP.cpp]
2026-09-29 switch to the Tallysman HC610 antenna and seat the 3D models on their pads
    [NAVCORE-SoOP-B_Cu.gbr, NAVCORE-SoOP-B_Mask.gbr, NAVCORE-SoOP-B_Paste.gbr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]
2026-09-30 re-lay with latching GH ports and ESD on every lead
    [BOM-NAVCORE-SoOP-economic.csv, BOM-NAVCORE-SoOP-nofpv.csv, BOM-NAVCORE-SoOP.csv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]
2026-10-01 model the mated plugs in the stack and re-lay Rev C to fit
    [BOM-NAVCORE-SoOP-economic.csv, BOM-NAVCORE-SoOP-nofpv.csv, BOM-NAVCORE-SoOP.csv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]
2026-10-02 rev D design: perimeter connectors, servo headers and an on-board antenna feed
    [NAVCORE-SoOP.kicad_sch, antenna_tower.stl, bias_strap.stl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]
2026-10-02 route Rev D and build its fab outputs
    [BOM-NAVCORE-SoOP-economic.csv, BOM-NAVCORE-SoOP-nofpv.csv, BOM-NAVCORE-SoOP.csv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]
2026-10-02 lower the skids to 45 mm so the LD06 clears the ground
    [frame.scad]
2026-10-02 bidirectional DShot on the motor timers, and one BOM variant fewer
    [BOM-NAVCORE-SoOP-nofpv.csv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]
2026-10-02 printed TPU skids, a Remote ID tray and sensor foam
    [antenna_tower.stl, drone.scad, gps_pod.stl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]
2026-10-05 respin design: clamps on every port, Remote ID and a tested MAX2112 setup
    [NAVCORE-SoOP.kicad_sch]
2026-10-05 route the respin and rebuild the fab outputs
    [BOM-NAVCORE-SoOP-economic.csv, BOM-NAVCORE-SoOP.csv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]
2026-10-05 fix the schematic export
    [NAVCORE-SoOP.kicad_sch]
2026-10-05 put the buck pin-1 dots by pad 1, drop duplicate vias and stubs
    [NAVCORE-SoOP-B_Cu.gbr, NAVCORE-SoOP-B_Mask.gbr, NAVCORE-SoOP-B_Paste.gbr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]

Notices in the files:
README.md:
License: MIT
